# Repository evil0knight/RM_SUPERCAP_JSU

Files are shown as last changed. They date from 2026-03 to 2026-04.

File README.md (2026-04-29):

# RM 超级电容控制器

本仓库整合了我的两个 RoboMaster 超级电容控制器项目。

| 项目 | 来源 | 主控 | 目录 |
| --- | --- | --- | --- |
| RM_SUPERCAP_JSU | 复刻桂林理工大学 | STM32G431 | [`gui_lin_li_gong/`](./gui_lin_li_gong/) |
| RM_SUPERCAP_JSU_V2 | 复刻香港科技大学 | STM32F334 | [`xiang_gang_ke_ji/`](./xiang_gang_ke_ji/) |

---

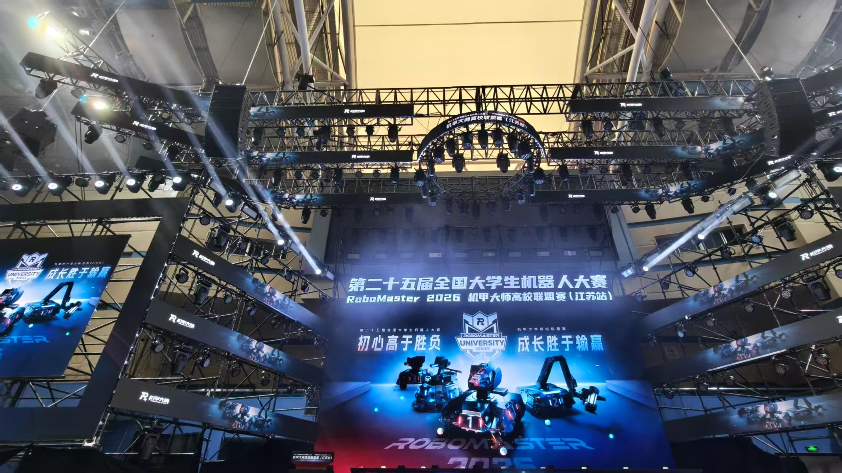
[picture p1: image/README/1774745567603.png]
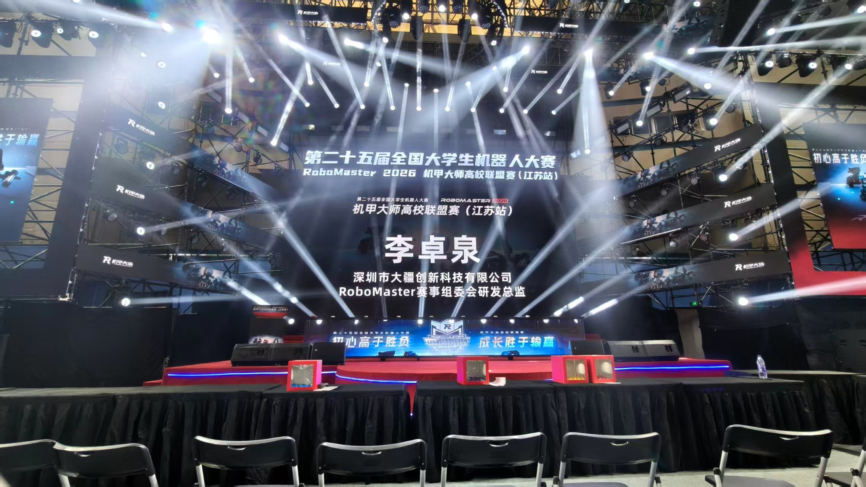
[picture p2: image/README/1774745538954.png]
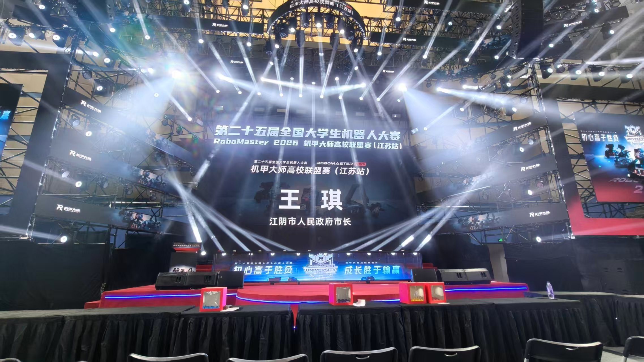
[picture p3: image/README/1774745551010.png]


## 一、RM_SUPERCAP_JSU（复刻桂林理工大学）

复刻 RM 桂林理工大学的开源
我们学校一直没有超电，或许我能填补这个空缺

**10.8**
已经做出来了，上车测试功能完好，能充电能放电，暂时没有遇到问题

**10.19**

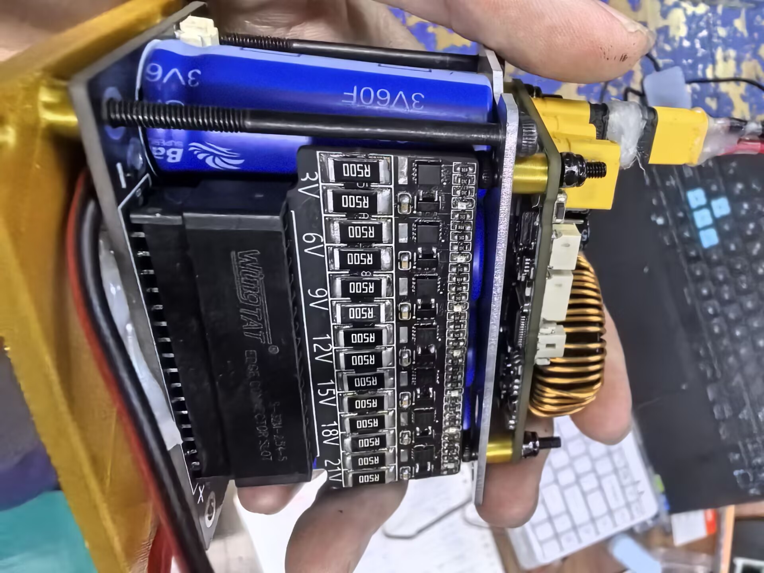
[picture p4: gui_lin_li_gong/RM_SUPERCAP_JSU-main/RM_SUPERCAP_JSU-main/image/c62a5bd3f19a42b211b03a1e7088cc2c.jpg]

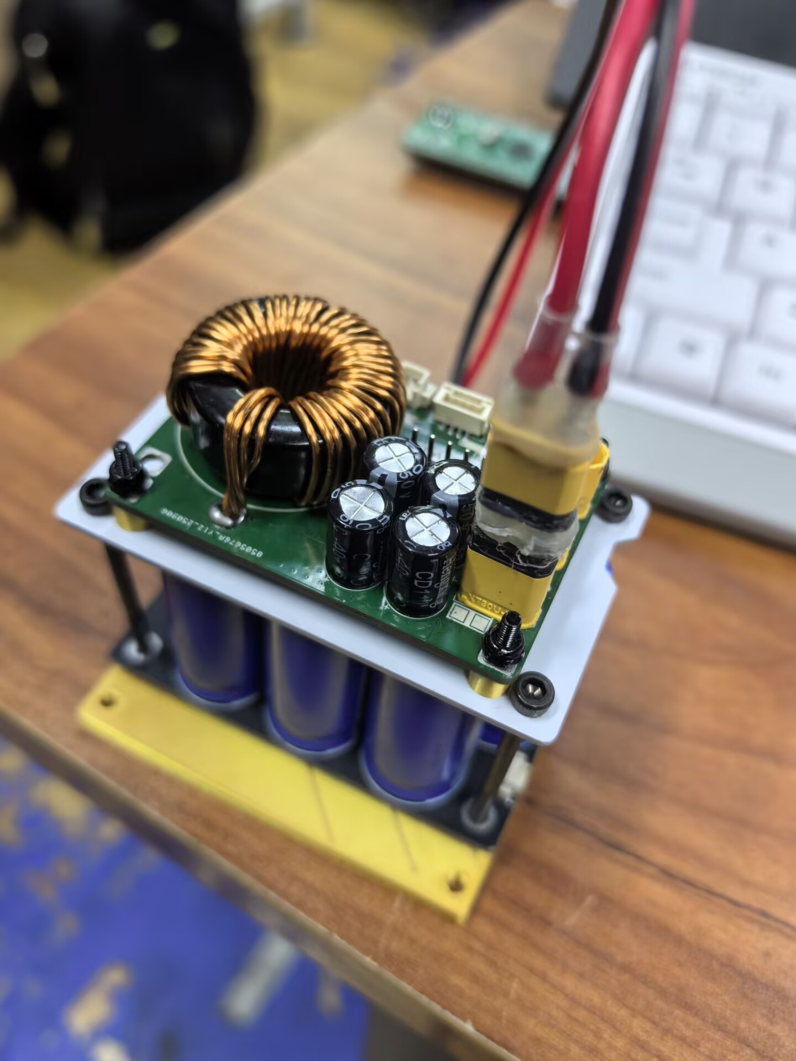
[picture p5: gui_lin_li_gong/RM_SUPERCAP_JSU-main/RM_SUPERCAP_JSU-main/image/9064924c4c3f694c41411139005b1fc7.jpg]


---

## 二、RM_SUPERCAP_JSU_V2（复刻香港科技大学）

复刻香港科技大学

**11.1**
现在的问题是电容端口短路，初步怀疑是原件选型错误，解决方法：加上了群里的同学一起讨论，和队里的研究生一起排查，看研究生的学习笔记，学习 C++

**11.13**
GAME WILL OVER，lucky，终于冲放电成功了，不报错，不过另一个的上板电流采样芯片可能坏了，等快递

**11.15**
研究生学姐走了，剩下的成果归本人所有

**11.18**
第二个也做出来了，一开始错误的原因是底盘电流检测芯片选型错误，要 INA240PW1 才是对的，INA240PW2 的增益是不同的
这如此种种也不过如此啊

**11.19**
炸了....

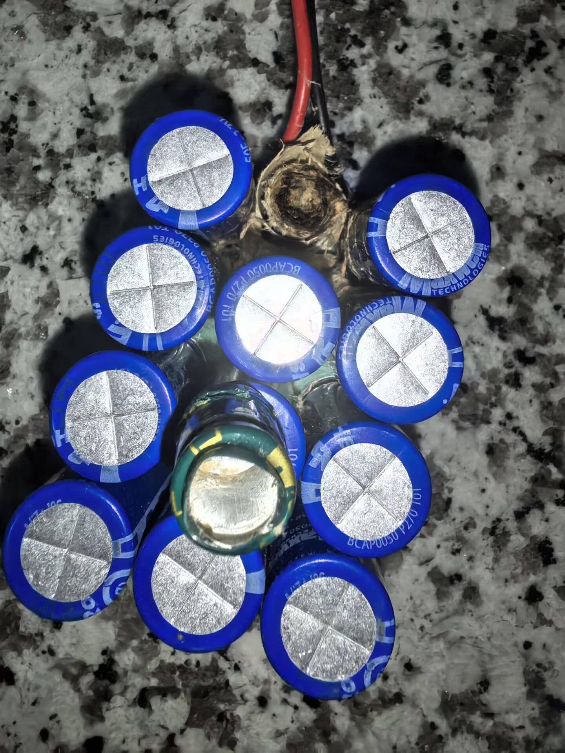
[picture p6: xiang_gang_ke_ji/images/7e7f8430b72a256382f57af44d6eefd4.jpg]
炸了


**11.20**
上车正常，最终效果：可以成功存储能量，要用的时候再输出，根据功率自动选择存储还是释放，功率闭环 + 缓冲能量闭环

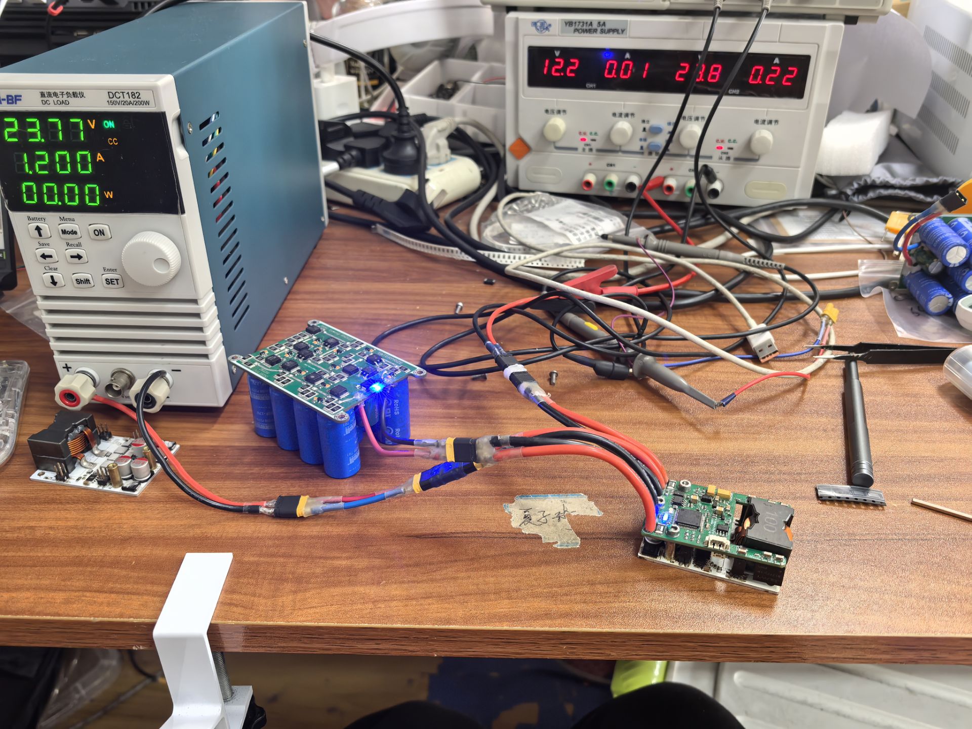
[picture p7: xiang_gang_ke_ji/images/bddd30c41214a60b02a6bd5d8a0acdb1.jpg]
上车


## 2026/4/28

我准备拿香港科技大学的硬件基础,重新写一遍程序,因为他里面有些地方有问题,很多人都是看不懂他们的代码,他们拿C++写的,就是为了炫技,同学们看不懂代码确实不好调,我拿C语言重新写一遍,不过这个项目要在打完所有比赛再开始,也算是我人生中为大学里的竞赛留下最后一点痕迹

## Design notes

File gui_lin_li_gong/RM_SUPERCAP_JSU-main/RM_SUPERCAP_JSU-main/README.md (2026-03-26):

# RM_SUPERCAP_JSU
复刻RM桂林理工大学的开源  
我们学校一直没有超电,或许我能填补这个空缺  

**10.8**  
已经做出来了,上车测试功能完好,能充电能放电,暂时没有遇到问题  
**10.19**  
示例图片
示例图片  
# SUPERCAP 超级电容控制器

基于 STM32G431 的 RoboMaster 超级电容功率控制系统

---

## 项目简介

SUPERCAP 是专为 RoboMaster 机器人设计的超级电容功率控制器。通过双向 BUCK-BOOST 电路实现超级电容的充放电管理，配合 CAN 总线通信与主控板协同工作，提升机器人瞬时功率输出能力。

---

## 工作原理

### 系统架构

控制器通过 CAN 总线接收 RM 主控板发送的以下指令：
- 系统使能信号
- 充电/放电模式切换
- 底盘功率上限
- 充电功率设定

### 充电模式

使用 BUCK-BOOST 电路对超级电容充电，实时检测充电电流和功率，通过 PID 算法控制 NMOS 栅极 PWM，精确调节充电电压。

### 放电模式

使用 BUCK-BOOST 电路向底盘供电，实时检测放电电流和电压，动态调整占空比以控制放电功率，满足功率限制要求。

---

## 硬件设计

### 核心器件

| 功能 | 型号 | 规格 |
|-----|---|---|
| 主控芯片 | STM32G431CBT6 | ARM Cortex-M4, 170MHz |
| 栅极驱动 | EG2181 | 高速半桥驱动器 |
| 半桥 MOS | WSD40120DN56G | 40V/120A |
| 关断 PMOS | WSD40L60DN56 | 40V/60A |
| 储能电感 | 106-125 磁环 | 22µH |
| 母线电流采样 | INA139 | 高侧电流检测 |
| 电容电流采样 | INA181A2 | 双向电流检测 |
| 辅助电源 | JW5026 + RT9193 | DC-DC + LDO |

### 设计工具

本项目使用 **KiCad 8.0** 进行硬件设计。

---

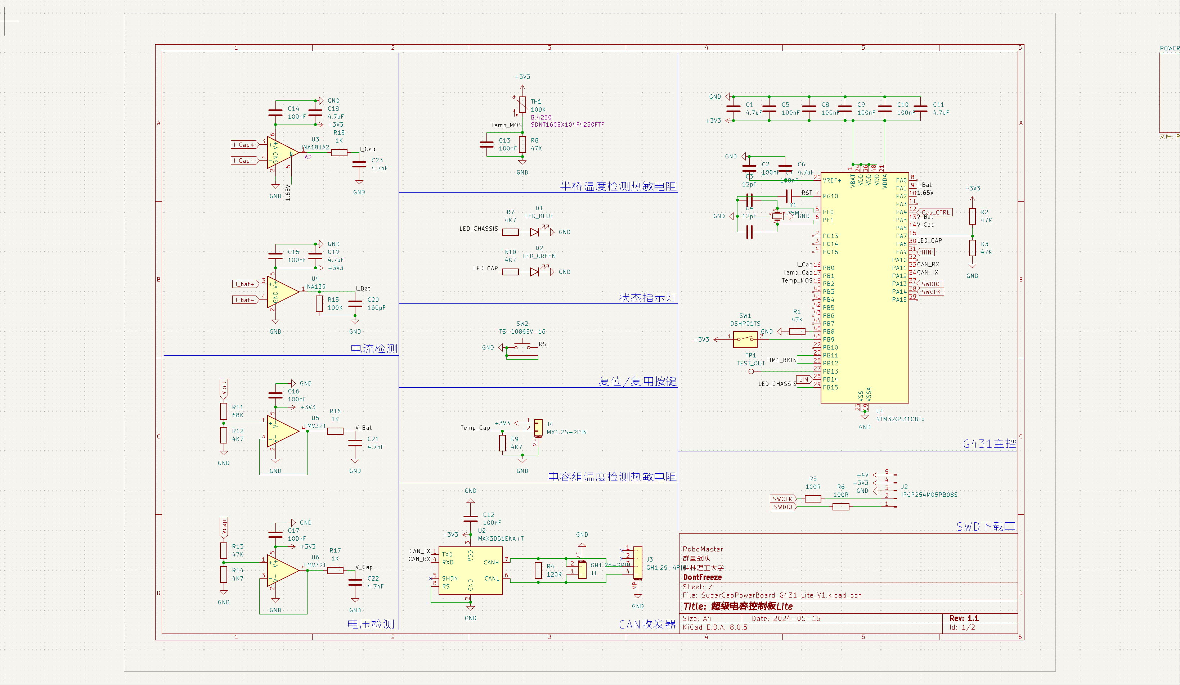
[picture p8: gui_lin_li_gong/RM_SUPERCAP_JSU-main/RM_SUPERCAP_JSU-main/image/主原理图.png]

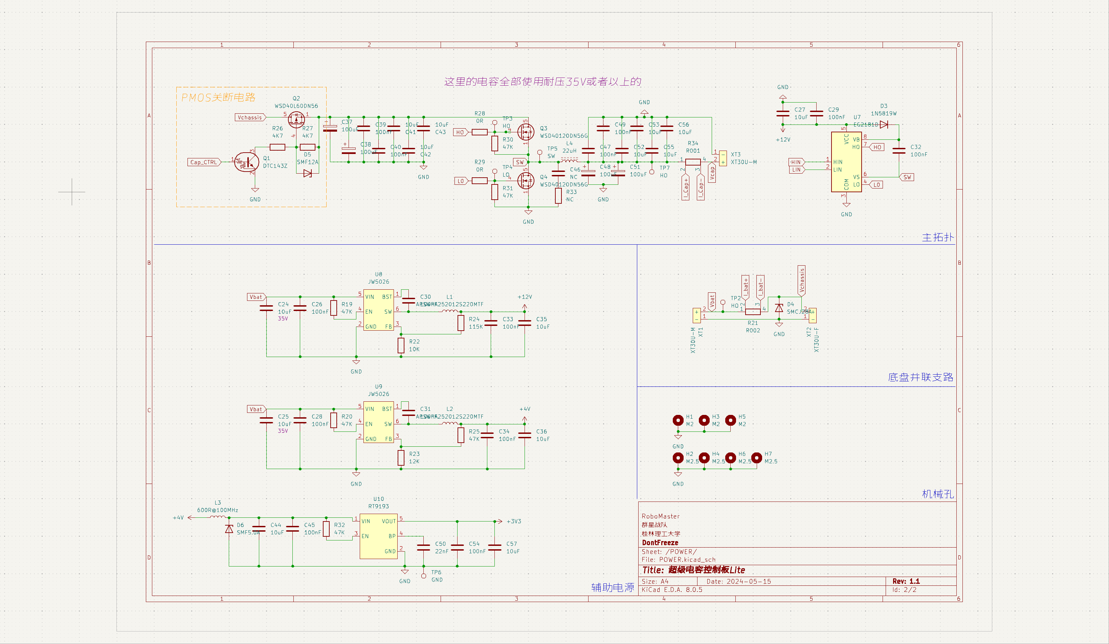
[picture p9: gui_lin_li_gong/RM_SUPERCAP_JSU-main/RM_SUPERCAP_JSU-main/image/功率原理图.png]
  

---
> **本项目主要面向HR。**

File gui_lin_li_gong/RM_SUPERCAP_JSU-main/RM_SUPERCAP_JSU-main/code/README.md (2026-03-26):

# 超级电容控制系统

## 🎯 主要功能
这是一个超级电容充放电控制系统，实现了智能功率管理、多重保护机制和CAN通信功能。

## 📊 系统架构

### 核心主函数
```c
void A_Timing_Ranking_Idea(void){
    TEST_OUT_HIGH;
    TimingCNT++;

    ADC_Convert_To_Reality();

    State_Change();
    Power_Loop();

    ADC_Value_AVG_Compute(DIV512); // 运行频率：100K/512 = 190hz

    if ((TimingCNT & DIV512) == 1) Power_Calculations();        // 运行频率：100K/128 = 190hz
    if ((TimingCNT & DIV512) == 2) Can_SendMess(&sCAN_TX_data); // 运行频率：100K/128 = 190hz
    // 计算平均值、功率计算、CAN发送。数据更新将以最慢的那个为准。

    if ((TimingCNT & DIV1024) == 10) CAN_ReceiveDataRefresh_Flag = 1; //刷新频率：100K/1024 = 97hz
    if ((TimingCNT & DIV8192) == 3) Temperature_Calculations(); // 运行频率：100K/8192 = 12hz
    if ((TimingCNT & DIV8192) == 10) LED_Refresh();             // 运行频率：100K/8192 = 12hz
    if ((TimingCNT & DIV8192) == 10) HAL_IWDG_Refresh(&hiwdg);  // 运行频率：100K/8192 = 12hz

    TEST_OUT_LOW;
}
```

> 💡 **建议**: 看代码时可以复制到新窗口，`A_Timing_Ranking_Idea(void)` 是整个系统的总脉络

## 🔧 关键函数说明

| 函数名 | 功能描述 | 运行频率 |
|---|---|---|
| `State_Change()` | 状态检测与切换 | 100KHz |
| `Power_Loop()` | 根据状态执行功率控制 | 100KHz |
| `ADC_Value_AVG_Compute()` | 计算ADC平均值供操作手查看 | 190Hz |
| `Power_Calculations()` | 功率计算并显示给操作手 | 190Hz |
| `Can_SendMess()` | CAN数据发送（已配置） | 190Hz |
| `Temperature_Calculations()` | 温度计算 | 12Hz |
| `LED_Refresh()` | LED状态刷新 | 12Hz |

### 🛠️ 初始化函数

- **`ADC_Curve_Fitting()`** - UID准备函数
- **`FDCAN_Filter_Init()`** - CAN通讯初始化
- **`Power_Loop_Parameter_Init()`** - 充放电参数初始化

## 📋 系统状态定义

### 超级电容状态枚举
```c
typedef enum
{
  DISCHARGE = 0,              // 放电
  CHARGE = 1,                 // 充电
  WAIT = 2,                   // 等待
  SOFRSTART_PROTECTION = 3,   // 软启动保护
  OCP_PROTECTION = 4,         // 过流保护
  OVP_BAT_PROTECTION = 5,     // 电池过压保护
  UVP_BAT_PROTECTION = 6,     // 电池欠压保护
  UVP_CAP_PROTECTION = 7,     // 电容欠压保护
  OTP_PROTECTION = 8          // 过温保护
} SuperCapStateTypeDef;
```

### 超级电容就绪状态
```c
typedef enum
{
  UNREADY = 0,    // 未就绪
  READY = 1,      // 就绪
} SuperCapReadyTypeDef;
```

## 🏷️ 数据结构

### 状态标志位
```c
typedef struct{
  uint8_t SoftStart_bit;     // 超级电容软起动
  uint8_t Charge_bit;        // 超级电容充电(1充电，0放电)
  uint8_t Enable_bit;        // 超级电容使能(1使能，0失能)
  
  uint8_t CAN_Offline_bit;   // 控制板CAN离线检测(1离线，0在线)
  uint8_t UVP_Bat_bit;       // 电池欠压保护(1欠压，0正常)
  uint8_t UVP_Cap_bit;       // 电容组过放保护(1过放，0正常)
  uint8_t OTP_MOS_bit;       // 控制板温度保护(1过温，0正常)
  uint8_t OTP_CAP_bit;       // 电容组过温保护(1过温，0正常)
  uint8_t OCP_bit;           // 控制板过流保护(1过流，0正常)
  uint8_t OVP_Cap_bit;       // 电容组过压保护(1过压，0正常)
  uint8_t OVP_Bat_bit;       // 控制板过压保护(1过压，0正常)
} StateFlagsTypeDef;
```

> 📝 **注释**: 本来计划使用位域定义，但调试时发现位域变量不显示变量名，因此使用uint8类型

### CAN通信数据结构

#### 📥 接收数据（电控发送）
```c
typedef struct {
  uint8_t Charge;                    // 充电控制(1充电，0放电)
  uint8_t Enable;                    // 使能控制(1使能，0失能)
  uint8_t PowerLimit;                // 裁判系统功率限制
  uint8_t ChargePower;               // 超级电容充电功率
  uint8_t Dead;                      // 机器人死亡状态(未使用)
  float PowerLimitAfterOffset;       // 偏移后功率限制
  float ChargePowerAfterOffset;      // 偏移后充电功率
} CAN_ReceiveDataTypeDef;
```

#### 📤 发送数据（发送给电控）
```c
typedef struct {
  uint8_t SuperCapEnergy;            // 超级电容可用能量(0-100%)
  uint8_t ChassisPower;              // 底盘实时功率(0-255W)
  SuperCapReadyTypeDef SuperCapReady; // 超级电容可用标志
  SuperCapStateTypeDef SuperCapState; // 超级电容状态标志
  uint8_t VoltageBat;                // 电池电压*10
  uint8_t DebugOut_BatPower;         // 调试输出电池功率
  int8_t DebugOut_SuperCapPower;     // 调试输出超电功率
} CAN_TransmitDataTypeDef;
```

### ADC数据结构
```c
typedef struct {
  uint32_t Vcap;    // 电容电压
  uint32_t Vbat;    // 电池电压
  uint32_t Ibat;    // 电池电流
  uint32_t Icap;    // 电容电流
  uint32_t Tmos;    // MOS管温度
  uint32_t Tcap;    // 电容温度
} ADC_ValueTypeDef;
```

> ⚠️ **注意**: 该结构体用途多样 - 既作为累加求和使用，也用于平均值计算，还用于瞬时控制

## 🚀 核心控制流程

### 1. 系统初始化
```c
void Power_Loop_Parameter_Init(void){
    TIM1_PWM2_BREAK;           // 关闭半桥PWM，防止初始值导致意外
    PMOS_OFF;                  // 关闭PMOS
    
    // 初始状态设置
    sStateBit.SoftStart_bit = 1;    // 开机必须软启动
    sStateBit.Charge_bit = 1;       // 默认充电状态
    sStateBit.Enable_bit = 0;       // 等待CAN使能
    sStateBit.CAN_Offline_bit = 1;  // 默认CAN离线
    
    // PID参数初始化
    // Buck电压环PID
    sPID_buck_V.Kp = PID_BUCK_V_KP;
    sPID_buck_V.Ki = PID_BUCK_V_KI;
    // ... 其他PID参数
}
```

### 2. 软启动保护
```c
void Soft_Start_Loop(void){
    // 软启动期间PMOS关闭，通过寄生二极管小电流充电
    if (sCAN_RX_data.Charge && sCAN_RX_data.Enable) {
        // 电流环控制
        PID_Compute(&sPID_buck_I, Icap, SOFTSTART_CHARGE_ICAP, &PID_CurrentLoopOut);
        // 电压环控制
        PID_Compute(&sPID_buck_V, Vcap, SOFTWARE_OVP_VCAP, &PID_VoltageLoopOut);
        
        // PWM输出竞争选择最小值
        Loop_Competition_Buck(PID_CurrentLoopOut, PID_VoltageLoopOut, &TIM1_PWM2_Comapre);
        
        // 设置PWM和ADC采样时间
        SET_PWM_COMPARE(TIM1_PWM2_Comapre);
        SET_ADC_TRIGGER_COMPARE((TIM1_PWM2_Comapre >> 3) + (TIM1_PWM2_Comapre >> 2));
        
        SuperCap_Enable();
    }
    
    // 充电到5V以上退出软启动
    if (Vcap > 5) {
        SaftChargeOutDelay++;
        if (SaftChargeOutDelay >= COUNT_TO_1S_ON_100Khz && sCAN_RX_data.Charge == CHARGE) {
            sStateBit.SoftStart_bit = 0;
            sStateBit.UVP_Cap_bit = 1;
        }
    }
}
```

### 3. 充电控制
```c
void Charge_Loop(void){
    // 安全功率限制
    SafeChargePcap = Vcap * SAFE_CHARGE_ICAP;
    P_ChargeCap = (sCAN_RX_data.ChargePowerAfterOffset > SafeChargePcap) ? 
                  SafeChargePcap : sCAN_RX_data.ChargePowerAfterOffset;
    
    // 功率环控制
    Pcap = Vcap * Icap;
    PID_Compute(&sPID_PowerLoop_Charge, Pcap, P_ChargeCap, &PID_PowerLoopOut);
    
    // 电压环控制
    PID_Compute(&sPID_buck_V, Vcap, SOFTWARE_OVP_VCAP, &PID_VoltageLoopOut);
    
    // 双环控制竞争
    Loop_Competition_Buck(PID_PowerLoopOut, PID_VoltageLoopOut, &TIM1_PWM2_Comapre);
    
    // 断电检测
    Power_Down();  // 检测电池电流，过低时失能电容组
}
```

### 4. CAN通信管理
```c
// 接收回调
void HAL_FDCAN_RxFifo0Callback(FDCAN_HandleTypeDef *hfdcan, uint32_t RxFifo0ITs){
    HAL_FDCAN_GetRxMessage(&hfdcan1, FDCAN_RX_FIFO0, &sFDCAN1_RxHeader, CAN_RX_Buff);
    CAN_WDG_Count = 0;  // 清零离线计数
}

// 离线处理
void CAN_Offline_Loop(void){
    SuperCap_Disable();
    // 清除所有PID积分
    
    if (CAN_WDG_Count == 1) {
        CAN_ONline_Delay++;
        // 连续收到10次充电指令才判断在线
        if (CAN_ONline_Delay >= 10 && sCAN_RX_data.Charge == CHARGE) {
            sStateBit.CAN_Offline_bit = 0;
        }
    }
}
```

## ⚡ PID控制说明

系统采用多环PID控制：
- **电压环**: 限制最大电压防止过压
- **电流环**: 限制最大电流防止过流  
- **功率环**: 控制充放电功率

> 🔧 **技巧**: 每个电压值对应特定占空比，通过 `PID->OutMax * 0.04f` 计算电压-占空比比例关系

## 📱 使用说明

1. **上电流程**: 系统自动进入软启动模式
2. **CAN通信**: 等待电控发送使能和充电指令
3. **状态监控**: 通过CAN实时上报系统状态
4. **保护机制**: 多重硬件和软件保护确保安全

## 🛡️ 安全特性

- ✅ 软启动保护防止冲击
- ✅ 过压/欠压保护
- ✅ 过流保护
- ✅ 过温保护  
- ✅ CAN通信看门狗
- ✅ 断电检测

---

> 💻 **开发建议**: 复制代码到新窗口查看，便于理解整体架构

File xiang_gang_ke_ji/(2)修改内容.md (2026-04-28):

# (2)修改

[←返回傻瓜使用教程](超电傻瓜式使用教程.md)

---

> 第二批买回来的原件,INA电流检测不准,具体点的问题是每次上电,I_A_CONVERT_BIAS都会变,基准值会变,光靠拟合是没用的,所以需要写一个补丁

> 所以我在每次上电的时候,读取IA和IB为0的时候的SampleManager::adcIA.sum和SampleManager::adcIB.sum

```
宏展开：
I = GAIN * (sum / 8) + BIAS
当 I = 0 时：
0 = GAIN * (sum_zero / 8) + BIAS
=> BIAS = -GAIN * (sum_zero / 8)
  所以只要在 I 确实为 0 的时候，读出 sum_zero，就能算出当次上电的 BIAS。
```

```
为什么 GAIN 不漂？
  GAIN 对应的是传感器的灵敏度（每安培对应多少 ADC 计数），这由硬件电阻、参考电压决定，温漂很小。
  为什么 BIAS 会漂？
  BIAS 对应的是零点电压，INA 运放的输入失调电压每次上电会有微小变化，导致 I=0 时 ADC 读数不固定，所以每次上电重新测一次零点。
```

```
前提条件：
校准时被测电流必须真的是 0
iA、iB 满足（buckboost 未工作）
iReferee 不满足（因为超电被供电的瞬间,电流是从电源端reference流向底盘chassis的,电流无法为0,除非先把连接底盘的xt30拔出来），所以不能动态校准
```

Core\Inc\calibration.hpp

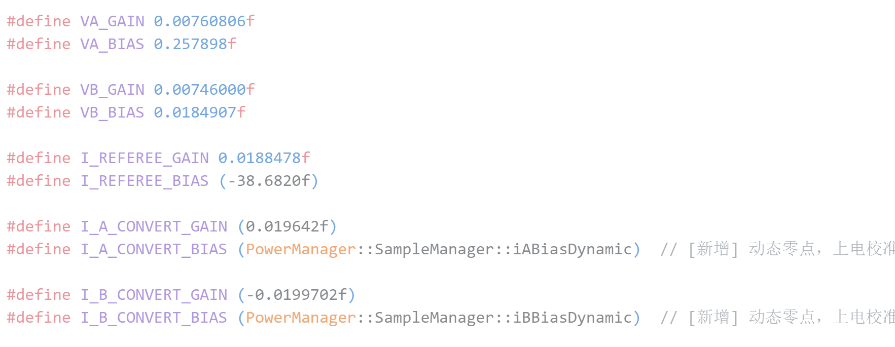
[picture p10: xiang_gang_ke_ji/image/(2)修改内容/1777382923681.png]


Core\Inc\PowerManager.hpp

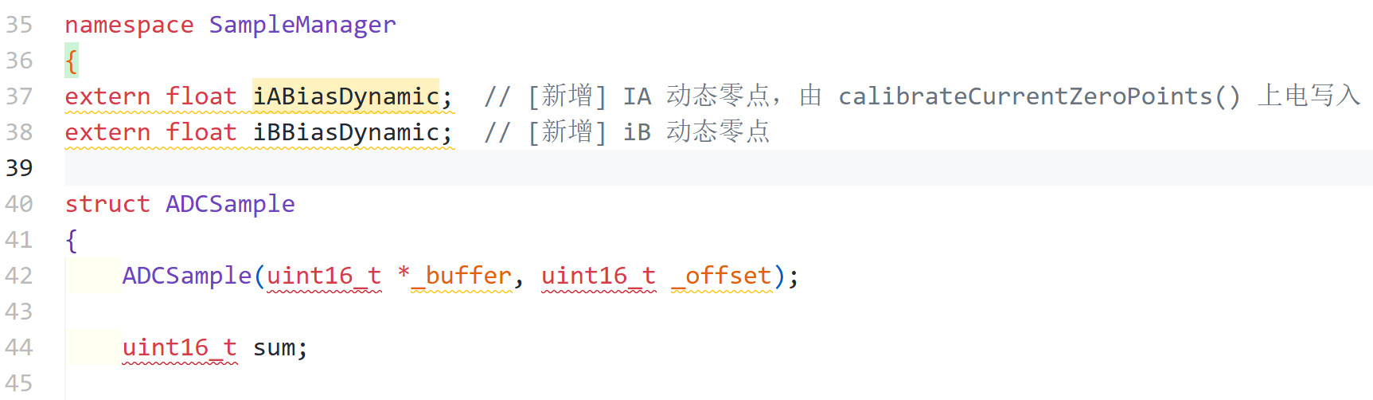
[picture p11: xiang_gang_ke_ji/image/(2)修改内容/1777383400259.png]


Core\Src\PowerManager.cpp

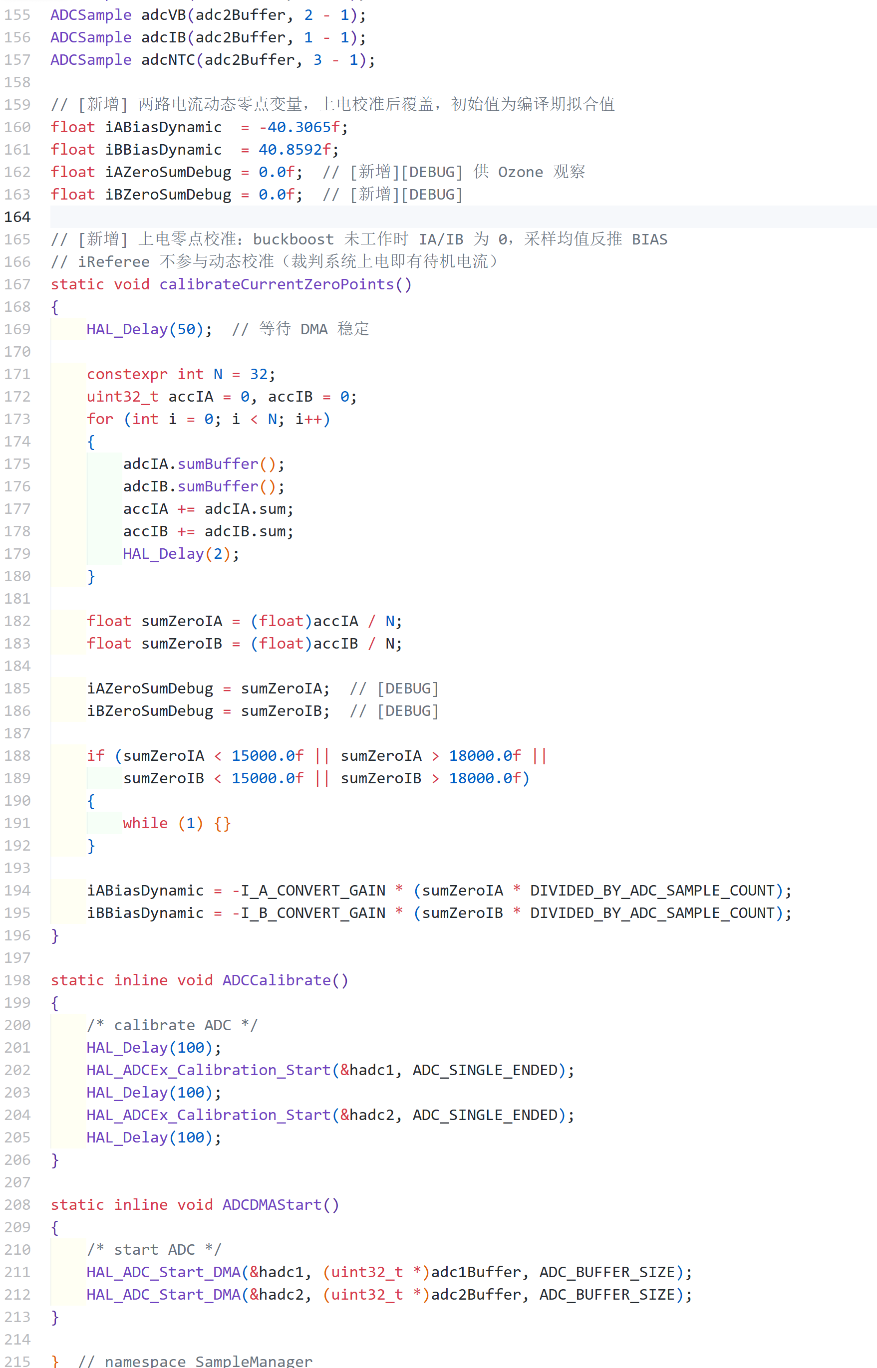
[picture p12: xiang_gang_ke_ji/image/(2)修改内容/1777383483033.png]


要是动态拟合有问题,超电会卡住while(1)

Core\Src\PowerManager.cpp

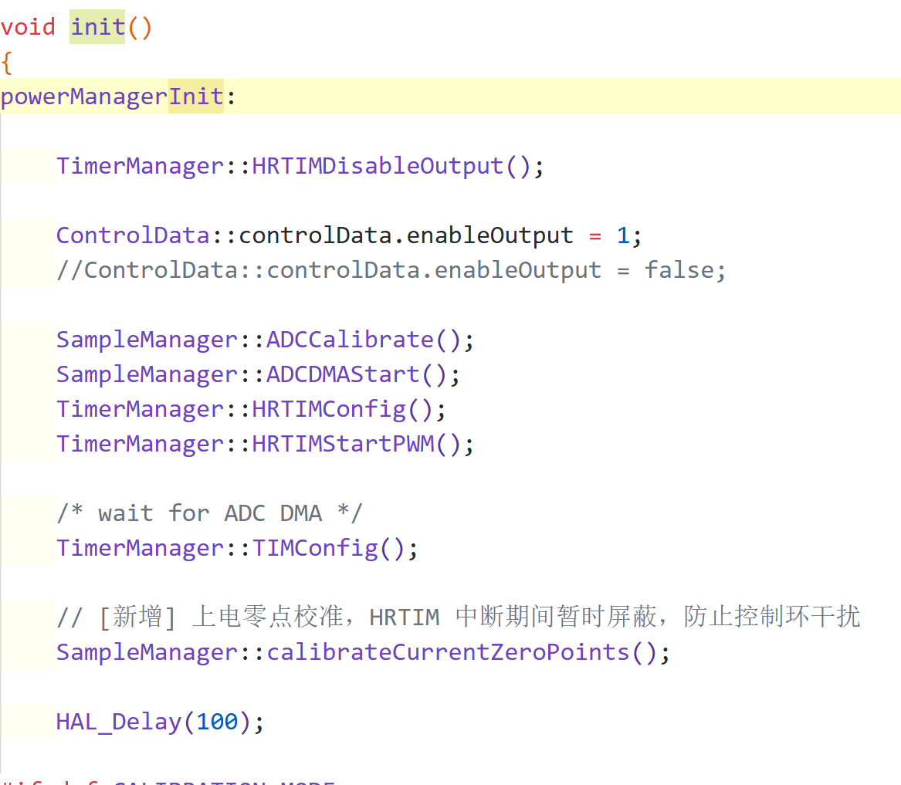
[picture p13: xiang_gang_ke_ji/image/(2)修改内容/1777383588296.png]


iReferee没办法了,超电没法阻断电流,但是没有动态拟合测算出来也差不多,没啥问题,

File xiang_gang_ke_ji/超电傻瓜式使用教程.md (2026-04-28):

# 超电傻瓜式使用教程

> 正常使用的超电不要改代码,下面的步骤是为了新做24超电,新作超电使用(2)
>
> (325)这个是给最早的两个超电,里面拟合好像有些不对,有时会报短路报错(不知道为什么,我猜还是拟合问题),需要车子一直给使能,不过能用,就留着吧
>
> (2)这个是新的超电,里面有修改原版代码,因为第二批买回来的INA芯片采样不准,每次上电的基准值都会发生变化,所以有修改

[(2)修改内容](2)修改内容.md)

## 📥 第一步：下载代码

这个编译学学可以，下载用OZONE
使用 **OZONE + JLink** 进行代码下载。
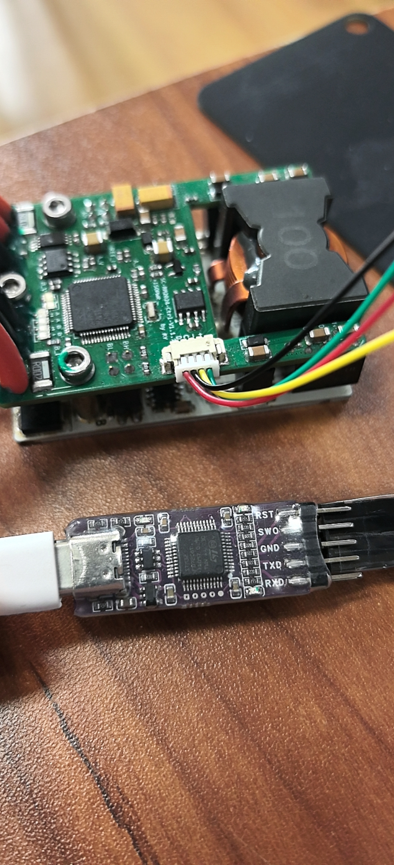
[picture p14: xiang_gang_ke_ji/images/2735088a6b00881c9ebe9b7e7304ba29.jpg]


---

## 🔧 第二步：修改硬件ID（新做超电必做）

如果要新做超电，**必须**使用 **STM32CubeProgrammer** 修改硬件ID。

### 操作步骤：

1. 打开 STM32CubeProgrammer
2. 连接设备
3. 将硬件ID修改为 **10x**

> 如果不修改硬件ID，(325)会无法下载,(2)蜂鸣器会一直响

> **操作示例：**
> 请参考示例图片进行操作
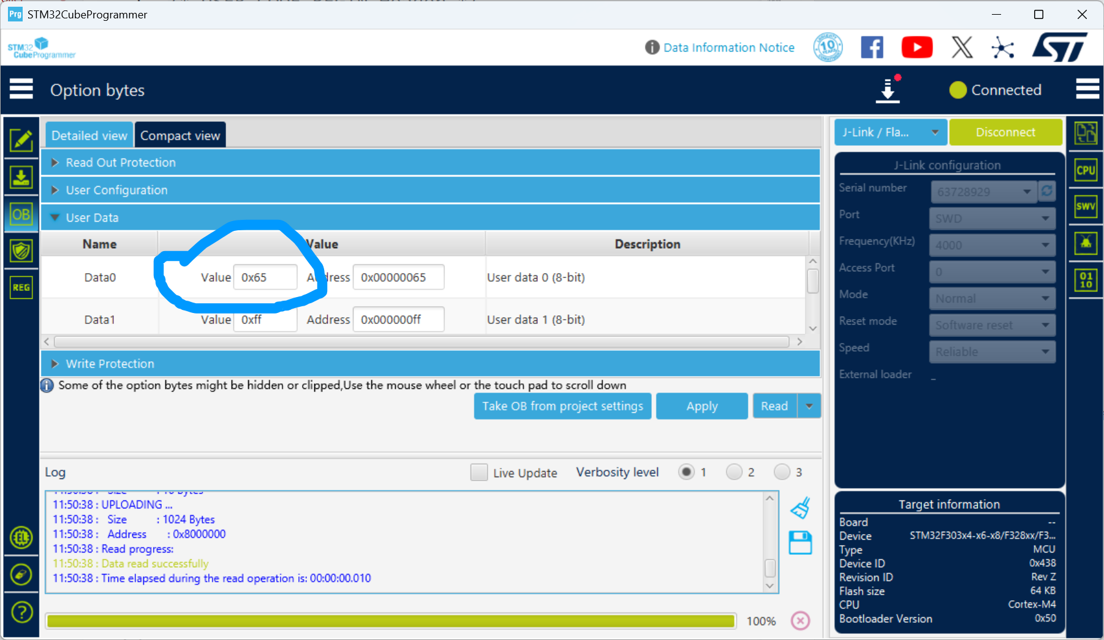
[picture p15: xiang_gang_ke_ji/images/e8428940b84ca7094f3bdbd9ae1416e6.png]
> 

---

## 第三步:编译

1. **ARM GCC 工具链** - `arm-none-eabi-gcc`
2. **CMake** - 版本 3.22 或更高
3. **Ninja** - 构建工具
4. **Git Bash** - Windows 环境下需要

### 📝 在 Git Bash 中编译

#### 1. 打开 Git Bash

在项目目录中右键，选择 "Git Bash Here"

#### 2. 给脚本添加执行权限（首次运行）

```bash
chmod +x build.sh
```

#### 3. 运行编译脚本

```bash
# 指定 HARDWARE_ID
./build.sh 101
```

## 第四步：测试

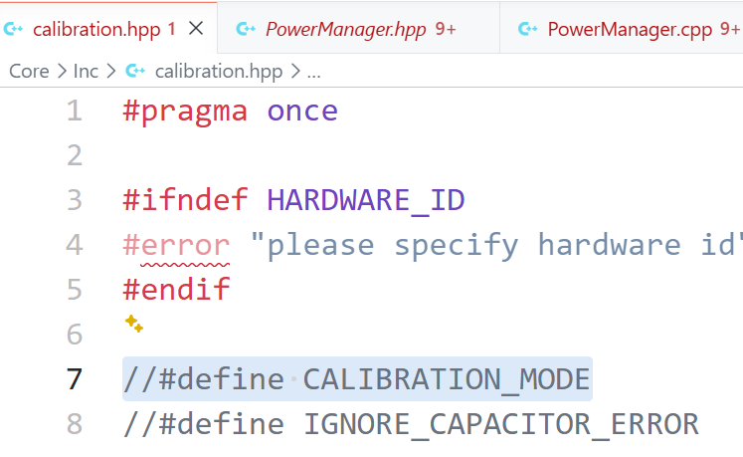
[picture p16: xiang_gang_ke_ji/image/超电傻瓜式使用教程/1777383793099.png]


这里取消注释

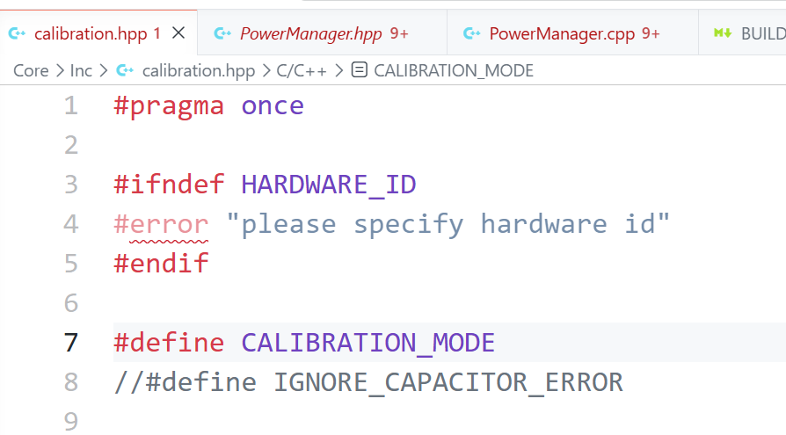
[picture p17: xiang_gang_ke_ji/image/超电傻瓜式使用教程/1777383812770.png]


然后编译,(2)会把上管打开,下管关闭

先开电源,然后下载进去,运行

此时应该是电源电压和负载仪的电压电流差不多,此时读出来的I就是要用来拟合的

---

## 拟合

拟合数据记录,然后丢给AI,让他帮你改Core\Inc\calibration.hpp这里的数值

这是IA端拟合示例

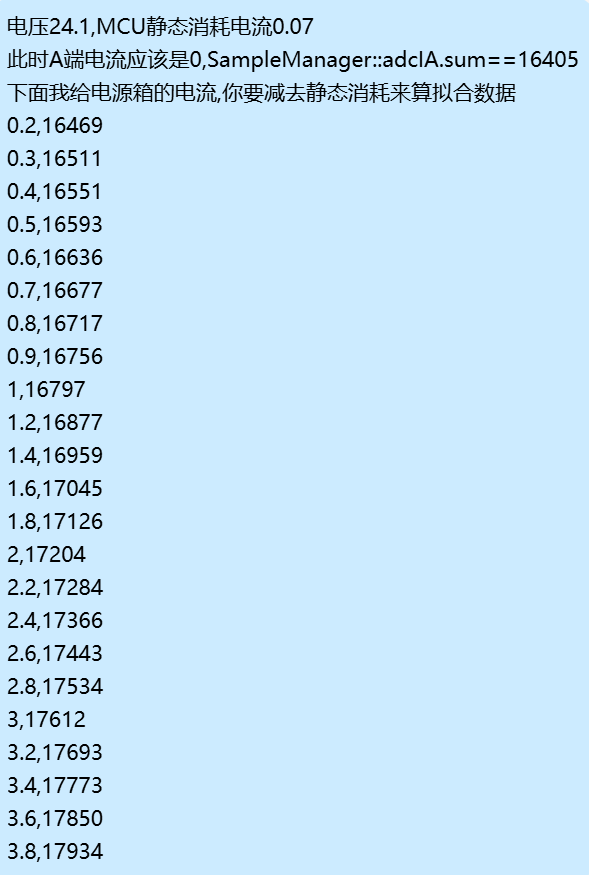
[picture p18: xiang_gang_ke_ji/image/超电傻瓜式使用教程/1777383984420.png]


VA拟合示例

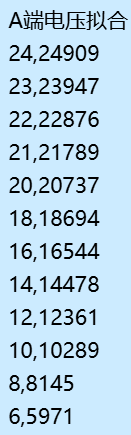
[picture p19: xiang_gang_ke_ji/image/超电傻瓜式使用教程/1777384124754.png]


B端拟合示例

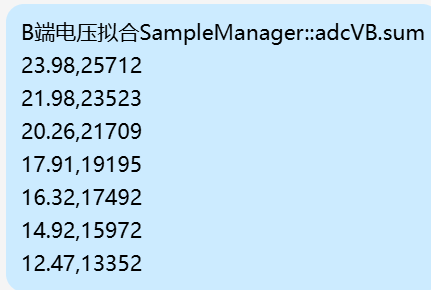
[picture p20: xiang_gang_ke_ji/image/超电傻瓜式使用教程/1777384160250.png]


IB拟合

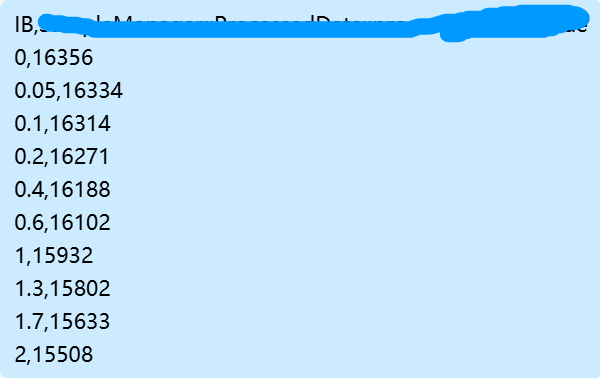
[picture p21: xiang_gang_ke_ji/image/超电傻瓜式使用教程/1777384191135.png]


ireference拟合示例

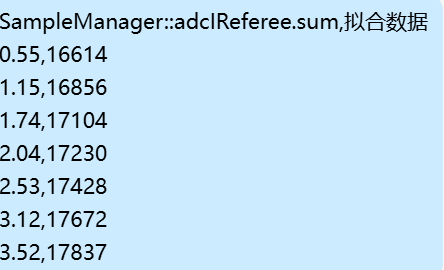
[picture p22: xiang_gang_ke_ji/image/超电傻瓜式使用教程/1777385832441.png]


拟合好就改回去//#define CALIBRATION_MODE

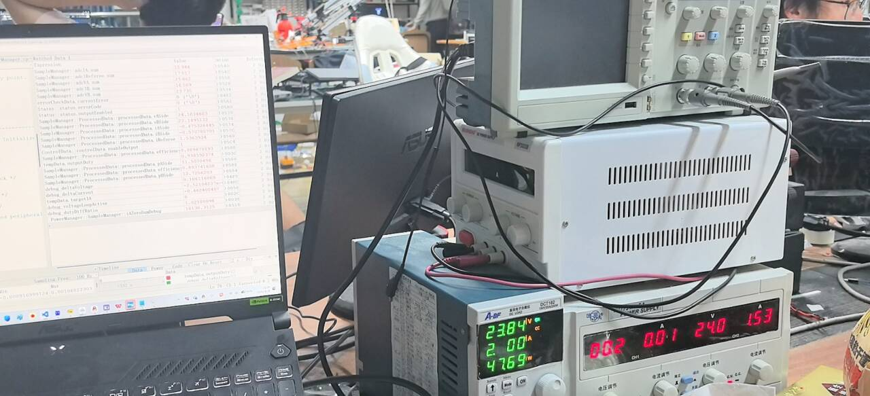
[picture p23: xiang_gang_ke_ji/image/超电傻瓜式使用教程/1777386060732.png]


---

## 🔌 接线说明

### 端口连接示意（从正面看）

```
┌─────────────────────────────────┐
│  左侧        中间        右侧    │
│ 电源(电管)  底盘(中心板)  电容   │
│  电流流入    电流流出    储能端  │
└─────────────────────────────────┘
```

- **右边**：接电容
- **中间**：接底盘（中心板）—— 电流流出
- **左边**：接电源（电管）

> **接线示例：**
> 请参考示例图片进行操作
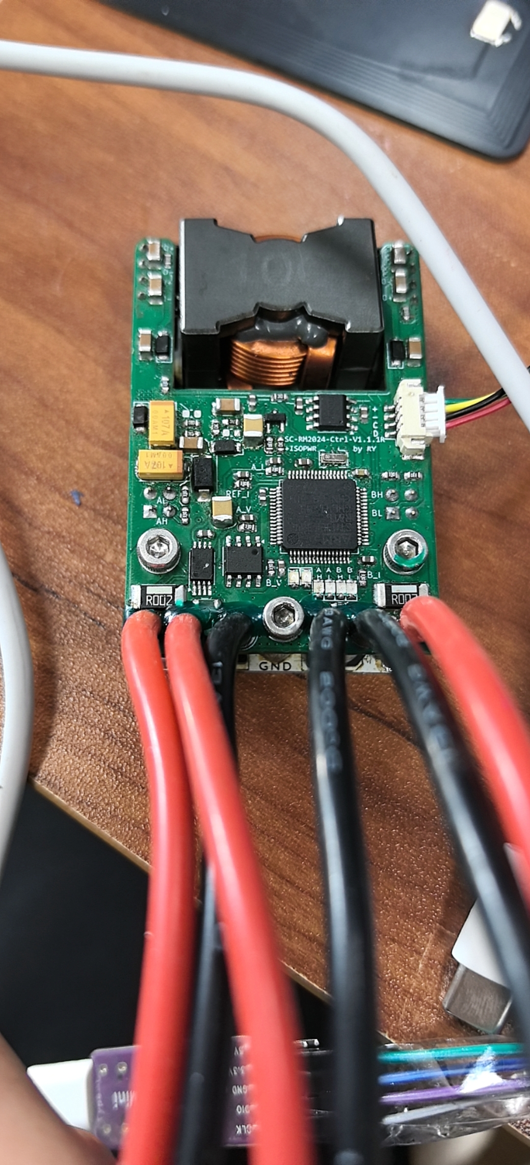
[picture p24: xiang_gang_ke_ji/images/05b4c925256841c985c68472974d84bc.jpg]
> 

---

## 🏁 超电裁判系统接法

> **接线示例：**
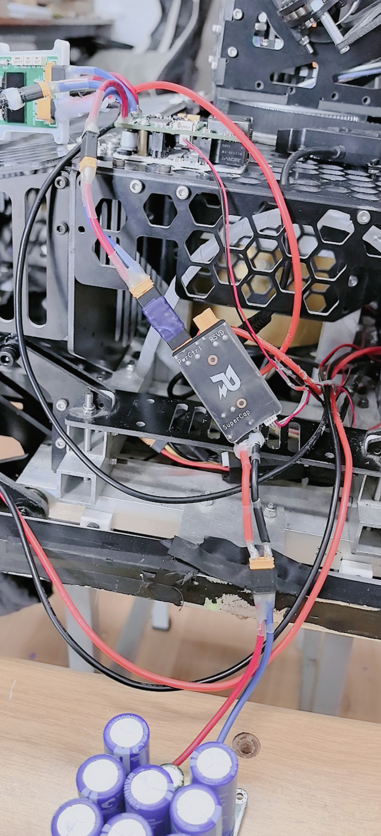
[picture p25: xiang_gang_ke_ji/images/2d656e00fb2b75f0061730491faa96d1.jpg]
> 

---

## 📡 第五步：CAN通信配置

xiang_gang_ke_ji\super_cap_extract_20260428
这里放的是车上的超电相关代码配置,我让AI读了英雄车上的代码,没怎么看
里面应该有个程序,好像是几秒就使能一下超电,这是因为最老的两个超电容易短路保护,这很奇怪,所以就一直使能就好了

---

## ✅ 完成

按照以上步骤操作，超电即可正常使用！1级580W的最大可使用功率!

---

*文档最后更新：2026/4/28*

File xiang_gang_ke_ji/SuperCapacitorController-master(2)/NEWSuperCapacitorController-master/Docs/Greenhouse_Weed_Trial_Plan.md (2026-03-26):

## 温室杂草识别试验方案（全垄布置）

### 1. 项目目标与地块概况
- **目标定位**：在全封闭温室内建立四条标准垄的杂草识别样地，专门采集低株高（≤`5 cm`）阶段的图像数据，同时保留托盘或边沟小区作种源补充。[2][3][4][7][8]
- **地块结构**：每条垄宽`0.50 m`、长`45.0 m`（面积`22.5 m²`），共四垄，总面积`90 m²`；垄间设置`0.30 m`巡查通道并铺防草布，垄尾保留`1.0 m × 1.0 m`缓冲区用于设备调头与物资堆放。
- **小区划分**：每条垄沿长度方向划分为A/B/C三个连续小区，每小区长`15.0 m`、宽`0.50 m`，面积`7.5 m²`。A/B/C用于重复采样或不同处理（如光照、补光、控水差异）。
- **识别优先原则**：四条垄全部用于识别样本采集，种源补育安排在垄尾托盘或另设基质槽，与主试验区完全隔离，避免影响拍摄。

### 2. 温室环境与通用管理
- **温度与湿度**：白天维持`16~18℃`、夜间`10~12℃`，相对湿度`60~70%`；必要时开启顶部通风与侧膜，防止徒长。[1]
- **光照**：保持棚膜洁净，阴天或冬季可补充LED顶光；如需遮阳，优先在轨道上方设置局部遮光布，保证拍摄光均匀。[1]
- **水肥策略**：播后7天内保持基质湿润，使用清水滴灌或喷雾；识别阶段停用氮肥，仅补充低浓度（≤`0.5 g/L`）平衡营养液，控制株高≤`5 cm`。[2][3]
- **防扩散措施**：四周加设20 cm深阻根膜，入棚设双门和脚踏消毒池；剪下的植株集中密封处理，防止种子逸散。[2][3]

### 3. 全垄识别布局原则
- **小区编号**：记为“垄号-小区”（例：`L1-A`），结合物种名称和轮次建立编码（例：`L1-A-CYP-01`）。
- **播种策略**：根据物种播幅在小区内布设2~4行，保证叶片铺满但不重叠；所有播量以下述小区面积（`15.0 m × 0.50 m`）为计算基准。
- **托盘补植**：每个物种额外准备2~4个`60 cm × 40 cm × 10 cm`基质托盘，放置在垄尾缓冲区，用于补播或备份。

### 4. 方案一：全垄单物种识别布置

> 轮次之间建议预留1周清园与闷棚时间，保证下一批次无残根残茎干扰。所有小区均保持单物种，便于精确控制密度、株高与背景。[2][3][7]

#### 轮次1（周期0~6周）：香附子 / 稗草 / 牛筋草 / 马唐
- **垄1 香附子**：
  - 小区尺寸：A/B/C各`0.50 m × 15.0 m`。
  - 栽植密度：行距`0.18 m`（3行），穴距`0.18 m`，每穴1块茎。
  - 种植密度：约`31`穴/m²；单小区约`230`穴，整垄约`690`穴。
  - 管理要点：覆土厚度`3 cm`，萌芽后保持株高≤`5 cm`，必要时摘除顶部叶片。[2]
- **垄2 稗草**：
  - 小区尺寸：A/B/C各`0.50 m × 15.0 m`。
  - 播种密度：行距`0.15 m`（4行），株距`0.05 m`。
  - 种植密度：约`133`株/m²；单小区播量约`110 g`（约`14.7 g/m²`），整垄约`330 g`。
  - 管理要点：保持2~3叶期拍摄，喷雾补水避免地表板结。[3]
- **垄3 牛筋草**：
  - 小区尺寸：A/B/C各`0.50 m × 15.0 m`。
  - 播种密度：行距`0.20 m`（3行），株距`0.08 m`。
  - 种植密度：约`63`株/m²；单小区播量约`70 g`（约`9.3 g/m²`），整垄约`210 g`。
  - 管理要点：分蘖超过3株时剪除侧蘖，保持叶片舒展。
- **垄4 马唐**：
  - 小区尺寸：A/B/C各`0.50 m × 15.0 m`。
  - 播种密度：行距`0.20 m`（3行），株距`0.06 m`。
  - 种植密度：约`83`株/m²；单小区播量约`80 g`（约`10.7 g/m²`），整垄约`240 g`。
  - 管理要点：拔节迹象出现即剪顶，结合补光获取均匀图像。[3]

#### 轮次2（周期7~12周）：马齿苋 / 反枝苋 / 小飞蓬 / 灰菜
- **垄1 马齿苋**：3行布局，行距`0.20 m`，株距`0.15 m`；种植密度约`33`株/m²，单小区约`250`株（整垄`750`株）；围设高度`10 cm`的PVC挡板防匍匐。
- **垄2 反枝苋**：3行，行距`0.25 m`，株距`0.10 m`；种植密度约`40`株/m²，单小区播量`50 g`（约`6.7 g/m²`，整垄`150 g`）；控水控肥使株高≤`5 cm`。[4]
- **垄3 小飞蓬**：4行，行距`0.18 m`，莲座株距`0.12 m`；种植密度约`46`株/m²，单小区播量`40 g`（约`5.3 g/m²`，整垄`120 g`），间苗至每小区约200株。
- **垄4 灰菜**：3行，行距`0.25 m`，株距`0.10 m`；种植密度约`40`株/m²，单小区播量`60 g`（约`8.0 g/m²`，整垄`180 g`）；保持植株直立，必要时轻度间苗。

#### 轮次3（周期13~18周）：龙葵 / 酸模叶蓼 / 狗尾巴草 / 蒲公英+车前
- **垄1 龙葵**：2行，行距`0.25 m`，穴距`0.20 m`；种植密度约`20`株/m²，单小区移栽苗约`60`株（整垄`180`株）；控温控氮保持株高≤`5 cm`，果实初显即剪除。[3]
- **垄2 酸模叶蓼**：3行，行距`0.30 m`，株距`0.15 m`；种植密度约`22`株/m²，单小区播量`45 g`（约`6.0 g/m²`，整垄`135 g`）；滴灌带两侧对称布置增强画面整齐度。
- **垄3 狗尾巴草**：4行，行距`0.15 m`，株距`0.10 m`；种植密度约`67`株/m²，单小区播量`60 g`（约`8.0 g/m²`，整垄`180 g`）；通过降温和剪顶将株高控制在`5 cm`以内。
- **垄4 蒲公英+车前**：各物种分配A/B/C小区的半幅（每物种面积`0.50 m × 7.5 m`），莲座密度`0.30 m × 0.20 m`；种植密度约`17`株/m²，单物种小区约`60`株，整垄约`180`株；抽薹即刻剪除。

#### 轮次4（周期19~24周）：附地菜 / 益母草 / 草木犀 / 野豌豆
- **垄1 附地菜群落**：4行，行距`0.20 m`，株距`0.10 m`；种植密度约`50`株/m²，单小区播量`35 g`（约`4.7 g/m²`，整垄`105 g`）；保持莲座状态。
- **垄2 益母草**：3行，行距`0.25 m`，株距`0.12 m`；种植密度约`33`株/m²，单小区播量`40 g`（约`5.3 g/m²`，整垄`120 g`）；株高接近`5 cm`即采集。
- **垄3 草木犀**：3行，行距`0.30 m`，株距`0.15 m`；种植密度约`22`株/m²，单小区播量`45 g`（约`6.0 g/m²`，整垄`135 g`）；低位绳网限制藤蔓高度。
- **垄4 野豌豆**：3行，行距`0.30 m`，株距`0.15 m`；种植密度约`22`株/m²，单小区播量`50 g`（约`6.7 g/m²`，整垄`150 g`）；设置低位绑蔓点保持苗期姿态。

### 5. 方案二：双物种同垄识别布置

> 依据设施混播管理资料，双物种条带或分段种植可提升数据多样性，但需增加隔离带与密度衰减，避免相互遮蔽。[5][11][12][13]

**组合搭配依据**
- 设施温室混播建议：农业农村部智慧种植模式强调可通过条带化或分段混播提升空间利用效率与数据多样性，但需设置隔离带并调低播量，避免相互遮蔽。[5]
- 块茎杂草与禾本科共管：香附子技术要点指出在高湿基质中可与禾本科共享水肥管理，只需降低禾本科播量并留出观测空间，因此组合1选择香附子+稗草并下调稗草密度。[3][11]
- 禾本科密植控制：稗草、牛筋草、马唐等一年生禾本科在密植条件下会相互遮挡，推广意见建议间苗或降低播量，组合2据此分段种植并下调播量以保持株高≤`5 cm`。[3]
- 阔叶杂草共生生态：研究表明马齿苋、反枝苋、小飞蓬、灰菜等阔叶杂草常在同一生境共存，但需控制密度和高度，组合3与组合4依靠分段、剪顶和围挡保持叶片清晰度。[12][13]
- 识别数据多样性：遥感与图像识别研究（WeedMap、DeepWeeds）显示多物种共存样本能提升模型泛化能力，但需维持单株轮廓清晰，因此方案二在保持株高≤`5 cm`的前提下采用条带隔离与密度衰减，兼顾可视性与多样性。[7][8]

- **分区方式**：每条垄仍宽`0.50 m`、长`45.0 m`，沿长度划分为前段（`0~22.5 m`）与后段（`22.5~45 m`）两个亚小区，各面积`11.25 m²`。
- **隔离带**：在两亚小区交界设置`0.5 m`宽防草布缓冲，或铺设可移动PVC板，减少根系互侵与影像干扰。
- **播种原则**：同垄内优先搭配1种禾本科+1种阔叶，或块茎+实生型，通过下调单物种播量20%降低竞争。[5][11]

#### 组合1（垄1：香附子 + 稗草）
- **前段（0~22.5 m）香附子**：行距`0.18 m`（3行），穴距`0.20 m`，每穴1块茎；种植密度约`28`穴/m²，单段约`320`穴，总播块茎`320~330`粒。[11]
- **后段（22.5~45 m）稗草**：行距`0.18 m`（3行），株距`0.06 m`；种植密度约`93`株/m²，单段播量约`150 g`（约`13.3 g/m²`）；通过间苗维持株高≤`5 cm`。[3]

#### 组合2（垄2：牛筋草 + 马唐）
- **前段牛筋草**：行距`0.22 m`（3行），株距`0.10 m`；种植密度约`45`株/m²，单段播量约`100 g`（约`8.9 g/m²`）；出苗后剪除多余分蘖。[3]
- **后段马唐**：行距`0.22 m`（3行），株距`0.08 m`；种植密度约`57`株/m²，单段播量约`115 g`（约`10.2 g/m²`）；拔节迹象出现即修剪顶端。[3]

#### 组合3（垄3：马齿苋 + 反枝苋）
- **前段马齿苋**：行距`0.22 m`（3行），株距`0.18 m`；种植密度约`25`株/m²，单段播量约`22 g`（约`2.0 g/m²`）；设置`10 cm`高围挡限制匍匐。[4]
- **后段反枝苋**：行距`0.25 m`（3行），株距`0.12 m`；种植密度约`33`株/m²，单段播量约`75 g`（约`6.7 g/m²`）；控制株高≤`5 cm`并保持叶面展开。[12]

#### 组合4（垄4：小飞蓬 + 灰菜）
- **前段小飞蓬**：行距`0.20 m`（4行），株距`0.14 m`；种植密度约`36`株/m²，单段播量约`65 g`（约`5.8 g/m²`），莲座期间苗至约`400`株。[13]
- **后段灰菜**：行距`0.25 m`（3行），株距`0.12 m`；种植密度约`33`株/m²，单段播量约`95 g`（约`8.4 g/m²`）；必要时薄剪顶部叶片保持可视度。

> 若需在双物种垄内增加第三条试验带，可在垄中央铺设`0.10 m`宽的黑色防草布，并沿布两侧布置低位定位桩，保证拍摄基准一致。[7]

### 6. 方案对比与选择建议

| 维度 | 方案一：全垄单物种 | 方案二：双物种同垄 | 管理提示 |
| --- | --- | --- | --- |
| 数据一致性 | 背景纯净、植株遮挡少，便于模型训练与参数对照。[7][8] | 图像更接近自然混生场景，可拓展模型泛化能力。[5][11] | 若首轮采集需建立基线，建议先采用方案一，再引入方案二增强多样性。 |
| 密度与播量 | 维持推荐密度即可；株高控制简单。[2][3] | 每物种播量需下调约20%，辅以隔离带与剪顶。[5][11] | 混播时实时记录两物种出苗差异，必要时错峰补播。 |
| 生长竞争 | 无杂草间竞争，管理工作量低。 | 存在光、水肥竞争，需增加巡查与局部调控。[12][13] | 建议在交界处预留缓冲带，定期翻检根系。 |
| 样本丰富度 | 每轮覆盖4个物种，需多轮才能完成全部名单。[7][8] | 单轮即可覆盖8个物种，数据多样性显著提升。[5][11] | 若采集周期有限，可优先使用方案二获取多物种样本。 |
| 设备协同 | 滑轨、补光等设备调校一次即可重复使用。 | 同垄不同物种需分段调光与调焦，摄影脚本更复杂。 | 可在方案二中预设拍摄脚本，或增加AI自动曝光。 |

> 综合建议：在模型冷启动或需精确衡量药效、株高控制时选择方案一；当目标转向提高训练数据多样性、模拟田间杂草互作时切换方案二。两方案可交替实施，以同一编码体系和日志模板保持数据可对比性。[5][7][8][11][12][13]

### 7. 设施识别周期作业节拍
- **周期第0周**：温室检修、消毒、铺滴灌；准备种源与标识物料。[1]
- **周期第1周**：播前浸种/催芽、建立小区标牌，完成摄影轨道或滑轨定位。
- **周期第2周**：播種或移栽，覆土≤`0.5 cm`，喷雾保湿。
- **周期第3周**：首次出苗调查，记录出苗率、株高、光照和湿度；试拍调参。
- **周期第4~6周**：按计划采集图像→剪顶→补播（如需）；记录每次操作时间与参数。
- **周期第7周**：结束轮次后清园、闷棚或蒸汽消毒7天，进入下一轮安排。

### 8. 日常执行要点
- 进棚前更换鞋套并在脚踏池消毒；作业工具按物种分区标记，防止交叉传播。
- 每日早晚巡查温湿度与株高，记录在Excel排程表中；一旦株高接近`5 cm`立即安排拍摄和剪顶。
- 拍摄后30分钟内完成剪顶及杂物清理，残体装袋焚烧或高温堆肥。
- 若需长时间补光，优先使用光谱一致的LED灯，并记录照度值供模型校正。

### 9. 图像数据采集与管理
- **采集窗口**：萌发后7~10天开始，每3~4天采集一次，直至株高接近`5 cm`；必要时在补播后错峰采集，丰富生育阶段样本。[7][8]
- **角度与光照**：每小区固定三个拍摄角度（俯视、斜视、侧视），使用灰度/色卡和尺标板（`30 cm × 30 cm`）置于画面固定位置。[7]
- **参数记录**：拍摄日志记录日期、时间、温湿度、光照强度、相机型号、镜头、曝光与增益设置；数据文件命名格式推荐`物种_垄号小区_轮次_时间戳_角度`。[8][9]
- **数据备份**：当日结束前上传至NAS或云端，保留RAW和压缩格式各一份；每轮次结束后进行元数据校验与样本质量评估。

### 10. 综合优势与风险控制
- **环境一致性**：固定垄宽与温室可控环境，使两种方案均处于低噪声条件，便于横向比较与模型复现。[1]
- **样本丰富度**：方案一通过多轮次覆盖全部物种，方案二在单轮内提供多物种混生数据，联合实施可快速构建不同组合的图像样本库。[7][8][10][11]
- **作业高效**：统一的“小区尺寸 + 编码规则”适用于两方案，便于排程、统计与自动化设备调用。
- **扩散风险控制**：剪顶、低氮和防草布等措施应用于两方案，可抑制种子逸散；混播段需额外巡查根系交缠情况。[2][3][5]
- **数据可追溯**：定位桩、色卡、日志与命名规范覆盖所有小区，方便将不同方案的数据统一存储与比对。[7][8][9]

### 11. 参考文献
[1] 中国科学院华南植物园. 《温室栽培指南》. https://scbg.cas.cn/old/ylyy/yyzp/201010/t20101002_2977855.html 访问日期：2025-11-04。
[2] 中国水稻研究所. 《稻田恶性杂草研究介绍》. https://cnrri.caas.cn/bsgk/xksz/dzjzyjyfzzx/276724.htm 访问日期：2025-11-04。
[3] 上海市农业技术推广服务中心. 《稻田杂草化学防除技术意见》. https://nyncw.sh.gov.cn/bcycyb/20180719/0009-76196.html 访问日期：2025-11-04。
[4] 全国农技推广中心. 《稻田杂草防控策略》. https://www.gzstv.com/a/3937d72bd2d24e60b3f8b9435d838178 访问日期：2025-11-04。
[5] 中华人民共和国农业农村部. 《国产化连栋温室智慧种植模式》. https://www.moa.gov.cn/ztzl/zhnyzxd/dfsj/202505/t20250512_6473867.htm 访问日期：2025-11-04。
[7] Milioto A, et al. "WeedMap: A Large-Scale Semantic Weed Mapping Framework using UAV Imagery." arXiv:1808.00100.
[8] Olsen A, et al. "DeepWeeds: A Multiclass Weed Species Image Dataset for Deep Learning." arXiv:1810.05726.
[9] Partel V, et al. "A Rapidly Deployable Classification System using Visual Data for Precision Weed Management." arXiv:1801.08613.
[10] Di Monte S. "A Random Planting Model." arXiv:2409.16432.
[11] 玉溪市农业农村局. 《香附子规模化种植技术要点》. https://m.yuxi.gov.cn/u/cms/yxszfxxgk/202401/18172458ypq5.pdf 访问日期：2025-11-04。
[12] 王勇, 等. 《珠三角地区四季草坪杂草群落组成及其生态位》. 生态学报, 2013. https://www.cje.net.cn/CN/abstract/abstract16493.shtml 访问日期：2025-11-04。
[13] 王敏, 等. 《川东北乡村不同生境中杂草多样性研究》. 四川农业大学学报, 2019. https://html.rhhz.net/STYNCHJXB/html/2019/11/20191108.htm 访问日期：2025-11-04。

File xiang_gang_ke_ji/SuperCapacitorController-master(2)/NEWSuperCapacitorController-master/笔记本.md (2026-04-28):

# *2024 超电重写*

## 4/19

IA测量不准确,用下载器供电,和电源箱供电,明明没有电流但是会有很大的电流测量出来,即使拟合了,每次上电测量值都不同,今天拿示波器测量的时候,因为不太会示波器(补一下[示波器笔记](https://evil0knight.github.io/quartz/%E6%9C%AF%E4%B8%AD%E8%87%AA%E6%9C%89%E4%B8%87%E9%92%9F%E7%B2%9F/%E7%A4%BA%E6%B3%A2%E5%99%A8),里面记录了烧了的原因),把芯片烧了,不过,正好把整个板子重新焊一边,

补一下之前几天遇到的问题,当时IA测量虽然不准但是还是能用的,是可以充放电的,但是到了电容充满的时候,会突然反灌电压,当时把电源电压抬到30v

还有一个情况是电源电压18往上,电容电压会被直接抬到33V

我认为这两者都是因为IA不准导致的,采样电阻是2mr的,适合大电流,对于小电流精度太低了,可是很奇怪的是IB是准的,所以我再猜是芯片有问题,所以这次芯片烧了正好把整个板子重新焊
[A端拟合数据](A 端电流拟合数据.xlsx)

还有一个焊接的细节,因为焊锡丝熔点不同,导致了焊接的困难,焊锡融化不了,使用小风热风枪吹下来,然后把锡拿吸锡带吸走

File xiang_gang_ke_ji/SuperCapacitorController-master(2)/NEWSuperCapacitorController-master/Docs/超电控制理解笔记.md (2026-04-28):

# 超电控制理解笔记

## 1. 当前总目标

### 1.2 系统在干什么

- 负载较小时：
- 负载较大时：
- 缓冲能量不足时：
- 电容电压过高时：

### 3.1 裁判/电池侧相关

- `refereePowerLimit`：
- `energyRemain`：
- `baseRefereePower`：
- `targetRefereePower`：
- `pReferee`：

### 3.2 超电/DC-DC相关

- `targetAPower`：
- `targetIA`：
- `iASide`：
- `vASide`：
- `vBSide`：
- `pBSide`：

### 3.3 最容易混淆的地方

- `baseRefereePower` 不是：
- `targetRefereePower` 不是：
- `pReferee` 更接近：
- `pBSide` 更接近：

## 4. 典型工况怎么理解

### 4.1 负载突然变大

- 观测到什么量变化：
- 哪个环先起作用：
- PWM 为什么会变：
- 超电是在充电还是放电：

### 4.2 负载较小

- 观测到什么量变化：
- 功率环会怎么调：
- 超电是在充电还是放电：

### 4.3 能量缓冲不足

- 代码位置：
- 当前看到的逻辑：
- 这代表“目标变成 10W”的是哪一路功率：
- 这不等于：
- 我自己的疑问：

### 4.4 电容电压过高

- 哪个环介入：
- 它是不是主串级环：
- 它更像限制还是主控制目标：

## 5. 关键问题记录

### 5.1 已确认

### 5.2 暂时不确定

### 5.3 之后要继续看代码确认

- `pReferee` 的具体计算式
- `pASide / pBSide` 的正负号定义
- A->B 和 B->A 时各变量物理意义
- `targetAPower` 的正负分别代表什么

## 6. 可直接补的结论草稿

### 6.1 整个超电就是想……

- 整个超电系统的核心，是通过双向 DC/DC 调节超电和底盘母线之间的功率流，让裁判/电池侧看到的功率尽量跟随一个动态目标。

### 6.2 为什么要多层环

- 功率不能直接靠 PWM 稳定执行，所以外层先决定“该给多少功率”，内层再用电流环把目标真正打到硬件上。

### 6.3 低缓冲时在干什么

- 当前代码表现为把裁判侧目标功率压到较低值，而不是简单写成“禁止使用超电”。

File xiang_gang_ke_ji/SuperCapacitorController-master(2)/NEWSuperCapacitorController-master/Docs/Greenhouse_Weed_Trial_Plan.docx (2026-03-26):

## 温室杂草识别试验方案（全垄布置）

### 1. 项目目标与地块概况

- 目标定位：在全封闭温室内建立四条标准垄的杂草识别样地，专门采集低株高（≤5 cm）阶段的图像数据，同时保留托盘或边沟小区作种源补充。[2][3][4][7][8]
- 地块结构：每条垄宽0.50 m、长45.0 m（面积22.5 m²），共四垄，总面积90 m²；垄间设置0.30 m巡查通道并铺防草布，垄尾保留1.0 m × 1.0 m缓冲区用于设备调头与物资堆放。
- 小区划分：每条垄沿长度方向划分为A/B/C三个连续小区，每小区长15.0 m、宽0.50 m，面积7.5 m²。A/B/C用于重复采样或不同处理（如光照、补光、控水差异）。
- 识别优先原则：四条垄全部用于识别样本采集，种源补育安排在垄尾托盘或另设基质槽，与主试验区完全隔离，避免影响拍摄。

### 2. 温室环境与通用管理

- 温度与湿度：白天维持16~18℃、夜间10~12℃，相对湿度60~70%；必要时开启顶部通风与侧膜，防止徒长。[1]
- 光照：保持棚膜洁净，阴天或冬季可补充LED顶光；如需遮阳，优先在轨道上方设置局部遮光布，保证拍摄光均匀。[1]
- 水肥策略：播后7天内保持基质湿润，使用清水滴灌或喷雾；识别阶段停用氮肥，仅补充低浓度（≤0.5 g/L）平衡营养液，控制株高≤5 cm。[2][3]
- 防扩散措施：四周加设20 cm深阻根膜，入棚设双门和脚踏消毒池；剪下的植株集中密封处理，防止种子逸散。[2][3]

### 3. 全垄识别布局原则

- 小区编号：记为“垄号-小区”（例：L1-A），结合物种名称和轮次建立编码（例：L1-A-CYP-01）。
- 播种策略：根据物种播幅在小区内布设2~4行，保证叶片铺满但不重叠；所有播量以下述小区面积（15.0 m × 0.50 m）为计算基准。
- 托盘补植：每个物种额外准备2~4个60 cm × 40 cm × 10 cm基质托盘，放置在垄尾缓冲区，用于补播或备份。

### 4. 方案一：全垄单物种识别布置

轮次之间建议预留1周清园与闷棚时间，保证下一批次无残根残茎干扰。所有小区均保持单物种，便于精确控制密度、株高与背景。[2][3][7]

#### 轮次1（周期0~6周）：香附子 / 稗草 / 牛筋草 / 马唐

- 垄1 香附子：
  - 小区尺寸：A/B/C各0.50 m × 15.0 m。
  - 栽植密度：行距0.18 m（3行），穴距0.18 m，每穴1块茎。
  - 种植密度：约31穴/m²；单小区约230穴，整垄约690穴。
  - 管理要点：覆土厚度3 cm，萌芽后保持株高≤5 cm，必要时摘除顶部叶片。[2]
- 垄2 稗草：
  - 小区尺寸：A/B/C各0.50 m × 15.0 m。
  - 播种密度：行距0.15 m（4行），株距0.05 m。
  - 种植密度：约133株/m²；单小区播量约110 g（约14.7 g/m²），整垄约330 g。
  - 管理要点：保持2~3叶期拍摄，喷雾补水避免地表板结。[3]
- 垄3 牛筋草：
  - 小区尺寸：A/B/C各0.50 m × 15.0 m。
  - 播种密度：行距0.20 m（3行），株距0.08 m。
  - 种植密度：约63株/m²；单小区播量约70 g（约9.3 g/m²），整垄约210 g。
  - 管理要点：分蘖超过3株时剪除侧蘖，保持叶片舒展。
- 垄4 马唐：
  - 小区尺寸：A/B/C各0.50 m × 15.0 m。
  - 播种密度：行距0.20 m（3行），株距0.06 m。
  - 种植密度：约83株/m²；单小区播量约80 g（约10.7 g/m²），整垄约240 g。
  - 管理要点：拔节迹象出现即剪顶，结合补光获取均匀图像。[3]

#### 轮次2（周期7~12周）：马齿苋 / 反枝苋 / 小飞蓬 / 灰菜

- 垄1 马齿苋：3行布局，行距0.20 m，株距0.15 m；种植密度约33株/m²，单小区约250株（整垄750株）；围设高度10 cm的PVC挡板防匍匐。
- 垄2 反枝苋：3行，行距0.25 m，株距0.10 m；种植密度约40株/m²，单小区播量50 g（约6.7 g/m²，整垄150 g）；控水控肥使株高≤5 cm。[4]
- 垄3 小飞蓬：4行，行距0.18 m，莲座株距0.12 m；种植密度约46株/m²，单小区播量40 g（约5.3 g/m²，整垄120 g），间苗至每小区约200株。
- 垄4 灰菜：3行，行距0.25 m，株距0.10 m；种植密度约40株/m²，单小区播量60 g（约8.0 g/m²，整垄180 g）；保持植株直立，必要时轻度间苗。

#### 轮次3（周期13~18周）：龙葵 / 酸模叶蓼 / 狗尾巴草 / 蒲公英+车前

- 垄1 龙葵：2行，行距0.25 m，穴距0.20 m；种植密度约20株/m²，单小区移栽苗约60株（整垄180株）；控温控氮保持株高≤5 cm，果实初显即剪除。[3]
- 垄2 酸模叶蓼：3行，行距0.30 m，株距0.15 m；种植密度约22株/m²，单小区播量45 g（约6.0 g/m²，整垄135 g）；滴灌带两侧对称布置增强画面整齐度。
- 垄3 狗尾巴草：4行，行距0.15 m，株距0.10 m；种植密度约67株/m²，单小区播量60 g（约8.0 g/m²，整垄180 g）；通过降温和剪顶将株高控制在5 cm以内。
- 垄4 蒲公英+车前：各物种分配A/B/C小区的半幅（每物种面积0.50 m × 7.5 m），莲座密度0.30 m × 0.20 m；种植密度约17株/m²，单物种小区约60株，整垄约180株；抽薹即刻剪除。

#### 轮次4（周期19~24周）：附地菜 / 益母草 / 草木犀 / 野豌豆

- 垄1 附地菜群落：4行，行距0.20 m，株距0.10 m；种植密度约50株/m²，单小区播量35 g（约4.7 g/m²，整垄105 g）；保持莲座状态。
- 垄2 益母草：3行，行距0.25 m，株距0.12 m；种植密度约33株/m²，单小区播量40 g（约5.3 g/m²，整垄120 g）；株高接近5 cm即采集。
- 垄3 草木犀：3行，行距0.30 m，株距0.15 m；种植密度约22株/m²，单小区播量45 g（约6.0 g/m²，整垄135 g）；低位绳网限制藤蔓高度。
- 垄4 野豌豆：3行，行距0.30 m，株距0.15 m；种植密度约22株/m²，单小区播量50 g（约6.7 g/m²，整垄150 g）；设置低位绑蔓点保持苗期姿态。

### 5. 方案二：双物种同垄识别布置

依据设施混播管理资料，双物种条带或分段种植可提升数据多样性，但需增加隔离带与密度衰减，避免相互遮蔽。[5][11][12][13]

组合搭配依据

设施温室混播建议：农业农村部智慧种植模式强调可通过条带化或分段混播提升空间利用效率与数据多样性，但需设置隔离带并调低播量，避免相互遮蔽。[5]

块茎杂草与禾本科共管：香附子技术要点指出在高湿基质中可与禾本科共享水肥管理，只需降低禾本科播量并留出观测空间，因此组合1选择香附子+稗草并下调稗草密度。[3][11]

禾本科密植控制：稗草、牛筋草、马唐等一年生禾本科在密植条件下会相互遮挡，推广意见建议间苗或降低播量，组合2据此分段种植并下调播量以保持株高≤5 cm。[3]

阔叶杂草共生生态：研究表明马齿苋、反枝苋、小飞蓬、灰菜等阔叶杂草常在同一生境共存，但需控制密度和高度，组合3与组合4依靠分段、剪顶和围挡保持叶片清晰度。[12][13]

识别数据多样性：遥感与图像识别研究（WeedMap、DeepWeeds）显示多物种共存样本能提升模型泛化能力，但需维持单株轮廓清晰，因此方案二在保持株高≤5 cm的前提下采用条带隔离与密度衰减，兼顾可视性与多样性。[7][8]

分区方式：每条垄仍宽0.50 m、长45.0 m，沿长度划分为前段（0~22.5 m）与后段（22.5~45 m）两个亚小区，各面积11.25 m²。

隔离带：在两亚小区交界设置0.5 m宽防草布缓冲，或铺设可移动PVC板，减少根系互侵与影像干扰。

播种原则：同垄内优先搭配1种禾本科+1种阔叶，或块茎+实生型，通过下调单物种播量20%降低竞争。[5][11]

#### 组合1（垄1：香附子 + 稗草）

- 前段（0~22.5 m）香附子：行距0.18 m（3行），穴距0.20 m，每穴1块茎；种植密度约28穴/m²，单段约320穴，总播块茎320~330粒。[11]
- 后段（22.5~45 m）稗草：行距0.18 m（3行），株距0.06 m；种植密度约93株/m²，单段播量约150 g（约13.3 g/m²）；通过间苗维持株高≤5 cm。[3]

#### 组合2（垄2：牛筋草 + 马唐）

- 前段牛筋草：行距0.22 m（3行），株距0.10 m；种植密度约45株/m²，单段播量约100 g（约8.9 g/m²）；出苗后剪除多余分蘖。[3]
- 后段马唐：行距0.22 m（3行），株距0.08 m；种植密度约57株/m²，单段播量约115 g（约10.2 g/m²）；拔节迹象出现即修剪顶端。[3]

#### 组合3（垄3：马齿苋 + 反枝苋）

- 前段马齿苋：行距0.22 m（3行），株距0.18 m；种植密度约25株/m²，单段播量约22 g（约2.0 g/m²）；设置10 cm高围挡限制匍匐。[4]
- 后段反枝苋：行距0.25 m（3行），株距0.12 m；种植密度约33株/m²，单段播量约75 g（约6.7 g/m²）；控制株高≤5 cm并保持叶面展开。[12]

#### 组合4（垄4：小飞蓬 + 灰菜）

- 前段小飞蓬：行距0.20 m（4行），株距0.14 m；种植密度约36株/m²，单段播量约65 g（约5.8 g/m²），莲座期间苗至约400株。[13]
- 后段灰菜：行距0.25 m（3行），株距0.12 m；种植密度约33株/m²，单段播量约95 g（约8.4 g/m²）；必要时薄剪顶部叶片保持可视度。

若需在双物种垄内增加第三条试验带，可在垄中央铺设0.10 m宽的黑色防草布，并沿布两侧布置低位定位桩，保证拍摄基准一致。[7]

### 6. 方案对比与选择建议

维度 | 方案一：全垄单物种 | 方案二：双物种同垄 | 管理提示
数据一致性 | 背景纯净、植株遮挡少，便于模型训练与参数对照。[7][8] | 图像更接近自然混生场景，可拓展模型泛化能力。[5][11] | 若首轮采集需建立基线，建议先采用方案一，再引入方案二增强多样性。
密度与播量 | 维持推荐密度即可；株高控制简单。[2][3] | 每物种播量需下调约20%，辅以隔离带与剪顶。[5][11] | 混播时实时记录两物种出苗差异，必要时错峰补播。
生长竞争 | 无杂草间竞争，管理工作量低。 | 存在光、水肥竞争，需增加巡查与局部调控。[12][13] | 建议在交界处预留缓冲带，定期翻检根系。
样本丰富度 | 每轮覆盖4个物种，需多轮才能完成全部名单。[7][8] | 单轮即可覆盖8个物种，数据多样性显著提升。[5][11] | 若采集周期有限，可优先使用方案二获取多物种样本。
设备协同 | 滑轨、补光等设备调校一次即可重复使用。 | 同垄不同物种需分段调光与调焦，摄影脚本更复杂。 | 可在方案二中预设拍摄脚本，或增加AI自动曝光。

综合建议：在模型冷启动或需精确衡量药效、株高控制时选择方案一；当目标转向提高训练数据多样性、模拟田间杂草互作时切换方案二。两方案可交替实施，以同一编码体系和日志模板保持数据可对比性。[5][7][8][11][12][13]

### 7. 设施识别周期作业节拍

- 周期第0周：温室检修、消毒、铺滴灌；准备种源与标识物料。[1]
- 周期第1周：播前浸种/催芽、建立小区标牌，完成摄影轨道或滑轨定位。
- 周期第2周：播種或移栽，覆土≤0.5 cm，喷雾保湿。
- 周期第3周：首次出苗调查，记录出苗率、株高、光照和湿度；试拍调参。
- 周期第4~6周：按计划采集图像→剪顶→补播（如需）；记录每次操作时间与参数。
- 周期第7周：结束轮次后清园、闷棚或蒸汽消毒7天，进入下一轮安排。

### 8. 日常执行要点

- 进棚前更换鞋套并在脚踏池消毒；作业工具按物种分区标记，防止交叉传播。
- 每日早晚巡查温湿度与株高，记录在Excel排程表中；一旦株高接近5 cm立即安排拍摄和剪顶。
- 拍摄后30分钟内完成剪顶及杂物清理，残体装袋焚烧或高温堆肥。
- 若需长时间补光，优先使用光谱一致的LED灯，并记录照度值供模型校正。

### 9. 图像数据采集与管理

- 采集窗口：萌发后710天开始，每34天采集一次，直至株高接近5 cm；必要时在补播后错峰采集，丰富生育阶段样本。[7][8]
- 角度与光照：每小区固定三个拍摄角度（俯视、斜视、侧视），使用灰度/色卡和尺标板（30 cm × 30 cm）置于画面固定位置。[7]
- 参数记录：拍摄日志记录日期、时间、温湿度、光照强度、相机型号、镜头、曝光与增益设置；数据文件命名格式推荐物种_垄号小区_轮次_时间戳_角度。[8][9]
- 数据备份：当日结束前上传至NAS或云端，保留RAW和压缩格式各一份；每轮次结束后进行元数据校验与样本质量评估。

### 10. 综合优势与风险控制

- 环境一致性：固定垄宽与温室可控环境，使两种方案均处于低噪声条件，便于横向比较与模型复现。[1]
- 样本丰富度：方案一通过多轮次覆盖全部物种，方案二在单轮内提供多物种混生数据，联合实施可快速构建不同组合的图像样本库。[7][8][10][11]
- 作业高效：统一的“小区尺寸 + 编码规则”适用于两方案，便于排程、统计与自动化设备调用。
- 扩散风险控制：剪顶、低氮和防草布等措施应用于两方案，可抑制种子逸散；混播段需额外巡查根系交缠情况。[2][3][5]
- 数据可追溯：定位桩、色卡、日志与命名规范覆盖所有小区，方便将不同方案的数据统一存储与比对。[7][8][9]

### 11. 参考文献

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

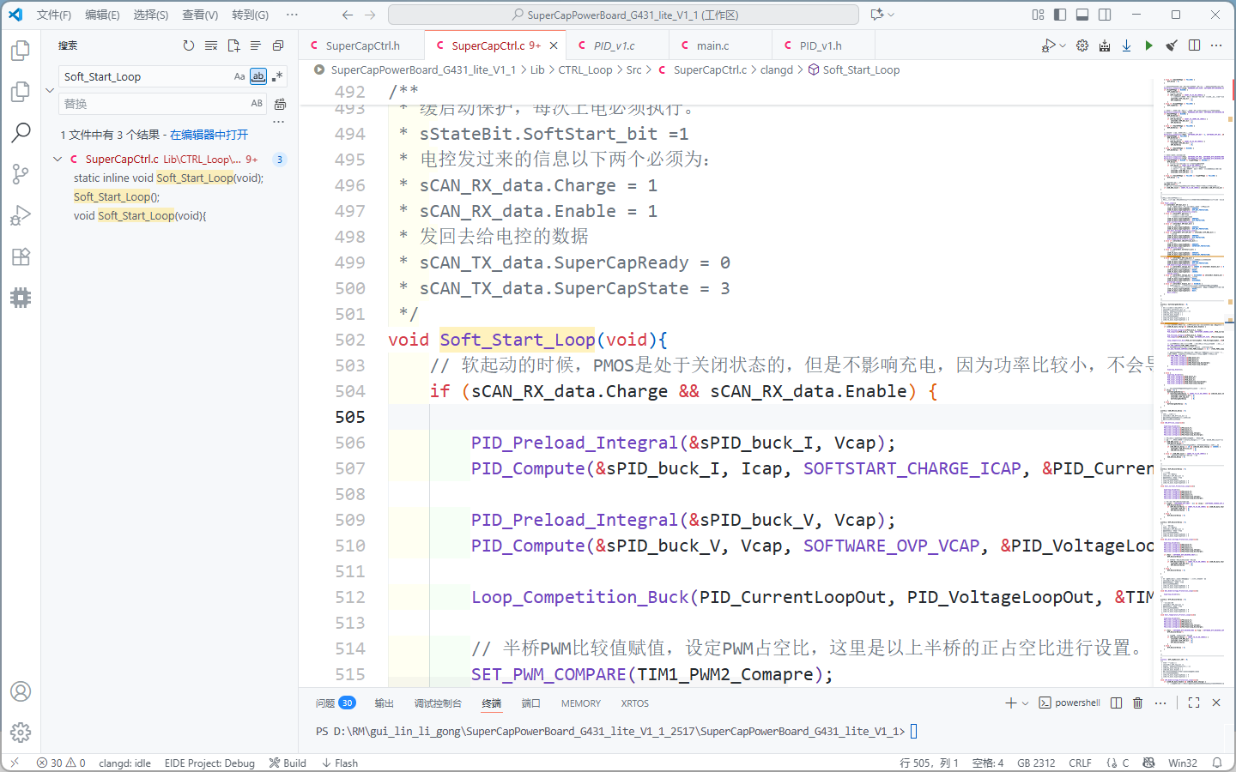
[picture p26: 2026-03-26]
gui_lin_li_gong/RM_SUPERCAP_JSU-main/RM_SUPERCAP_JSU-main/image/4af9171b36c758007bd921bbe818e17b.png

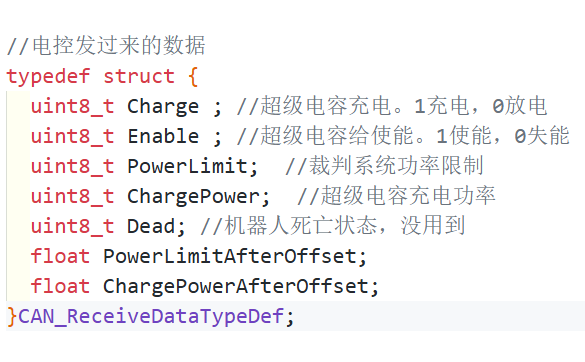
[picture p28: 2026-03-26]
gui_lin_li_gong/RM_SUPERCAP_JSU-main/RM_SUPERCAP_JSU-main/image/6200439e373334d2f63a813156c07891.png

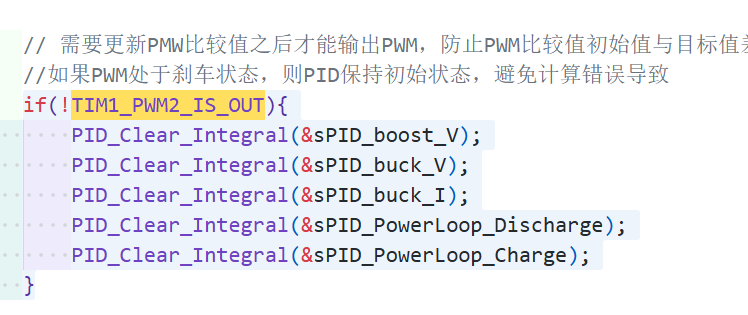
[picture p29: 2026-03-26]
gui_lin_li_gong/RM_SUPERCAP_JSU-main/RM_SUPERCAP_JSU-main/image/fabafc9a1ea7090c792672b683ed3a64.png

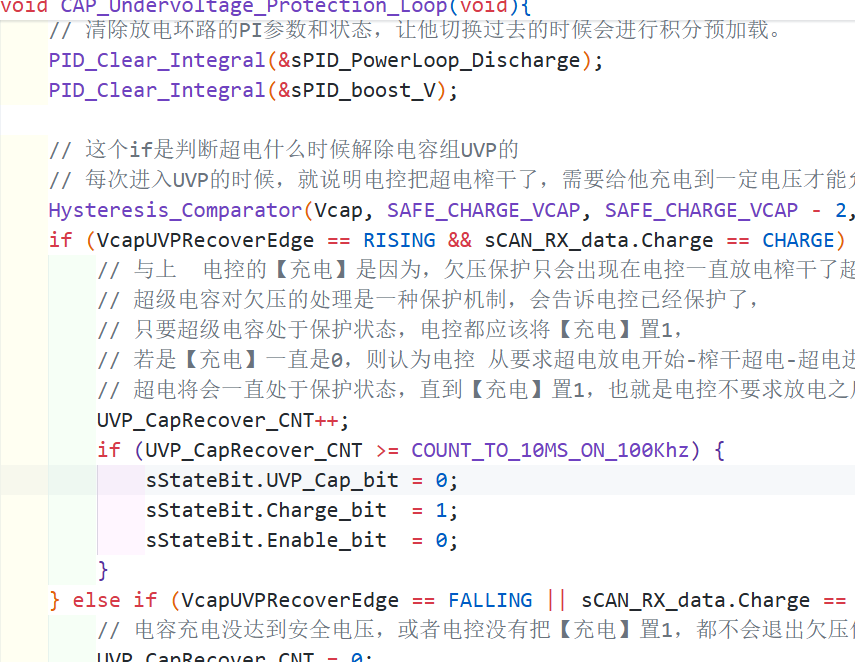
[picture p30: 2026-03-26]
gui_lin_li_gong/RM_SUPERCAP_JSU-main/RM_SUPERCAP_JSU-main/image/4f95a043e1c274b82a52535207094248.png

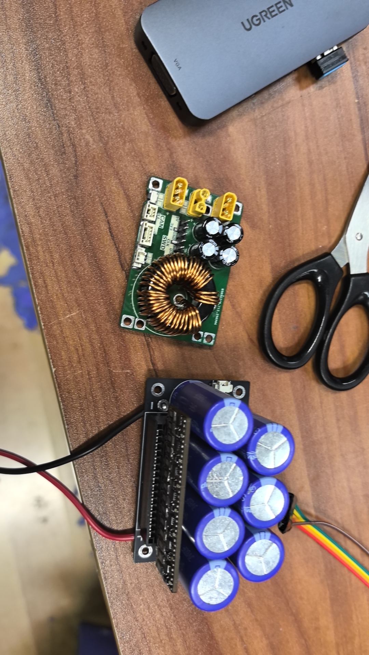
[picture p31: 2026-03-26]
gui_lin_li_gong/RM_SUPERCAP_JSU-main/RM_SUPERCAP_JSU-main/image/wx_camera_1759242208115.jpg

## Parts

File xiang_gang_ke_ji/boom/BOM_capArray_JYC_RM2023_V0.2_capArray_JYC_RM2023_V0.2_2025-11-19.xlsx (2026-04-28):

No. | Quantity | Comment | Designator | Footprint | Value | Manufacturer Part | Manufacturer | Supplier Part | Supplier | JLCPCB Price | JLCPCB Stock
1 | 10 | 50F | C1,C2,C3,C4,C5,C6,C7,C8,C9,C10 | Capacitor_THT:CP_Radial_D18.0mm_P7.50mm
2 | 1 | 50F | C11 | Capacitor_THT:CP_Radial_D18.0mm_P7.50mm | 50F
3 | 1 | 2200uf | C12 | Capacitor_THT:CP_Radial_D18.0mm_P7.50mm
4 | 11 | LED | D1,D2,D3,D4,D5,D6,D7,D8,D9,D10,D11 | LED_SMD:LED_0603_1608Metric
5 | 1 | LED | D12 | LED_SMD:LED_0603_1608Metric | LED
6 | 1 | SMCJ30A | D13 | Diode_SMD:D_SMC | SMCJ30A
7 | 1 | MountingHole_Pad | H1 | MountingHole:MountingHole_2.2mm_M2_Pad_Via
8 | 1 | MountingHole_Pad | H2 | MountingHole:MountingHole_2.2mm_M2_Pad_Via | MountingHole_Pad
9 | 1 | MountingHole_Pad | H3 | MountingHole:MountingHole_3.2mm_M3_Pad_Via | MountingHole_Pad
10 | 3 | MountingHole_Pad | H4,H5,H6 | MountingHole:MountingHole_3.2mm_M3_Pad_Via
11 | 10 | Q_NMOS_GDS | Q1,Q3,Q4,Q5,Q6,Q7,Q8,Q9,Q10,Q11 | Package_TO_SOT_SMD:TO-252-2
12 | 1 | Q_NMOS_GDS | Q2 | Package_TO_SOT_SMD:TO-252-2 | Q_NMOS_GDS
13 | 32 | 1k | R1,R2,R3,R4,R8,R9,R10,R14,R15,R16,R20,R21,R22,R23,R24,R25,R26,R27,R28,R29,R30,R31,R37,R46,R47,R48,R53,R54,R55,R57,R58,R59 | Resistor_SMD:R_0603_1608Metric
14 | 32 | R300 | R5,R6,R7,R11,R12,R13,R17,R18,R19,R33,R34,R35,R36,R38,R39,R40,R42,R43,R44,R45,R49,R50,R51,R61,R62,R63,R65,R66,R67,R69,R70,R71 | Resistor_SMD:R_2512_6332Metric_Pad1.40x3.35mm_HandSolder
15 | 1 | 1k | R32 | Resistor_SMD:R_0603_1608Metric | 1k
16 | 1 | R300 | R41 | Resistor_SMD:R_2512_6332Metric_Pad1.40x3.35mm_HandSolder | R300
17 | 1 | 5.1k | R52 | Resistor_SMD:R_0603_1608Metric
18 | 10 | ~ | U1,U2,U3,U4,U5,U6,U7,U8,U9,U10 | Package_TO_SOT_SMD:SOT-23-5
19 | 1 | ~ | U11 | Package_TO_SOT_SMD:SOT-23-5 | ~

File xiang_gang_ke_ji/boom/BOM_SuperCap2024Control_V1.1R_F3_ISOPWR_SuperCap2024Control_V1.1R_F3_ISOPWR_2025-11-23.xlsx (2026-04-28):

No. | Quantity | Comment | Designator | Footprint | Value | Manufacturer Part | Manufacturer | Supplier Part | Supplier | JLCPCB Price | JLCPCB Stock
1 | 1 | Device_Buzzer | BZ1 | 0_RM2024:MLT-9032 | Buzzer-9032
2 | 26 | Device_C | C1,C8,C10,C11,C12,C13,C14,C17,C19,C20,C21,C22,C23,C24,C25,C26,C27,C28,C29,C30,C31,C32,C33,C39,C41,C47 | Capacitor_SMD:C_0603_1608Metric | 100n
3 | 3 | Device_C_Polarized | C2,C6,C7 |  | C_Polarized
4 | 7 | Device_C | C3,C5,C15,C16,C34,C40,C42 | Capacitor_SMD:C_0603_1608Metric | 10u
5 | 1 | Device_C | C4 | Capacitor_SMD:C_0603_1608Metric | 20p
6 | 12 | Device_C | C9,C18,C36,C37,C44,C45,C49,C50,C52,C53,C54,C55 | Capacitor_SMD:C_1206_3216Metric | 10u
7 | 2 | Device_C | C35,C48 | Capacitor_SMD:C_0603_1608Metric | 100p
8 | 2 | Device_C_Polarized | C38,C46 | Capacitor_Tantalum_SMD:CP_EIA-6032-28_Kemet-C | C_Polarized
9 | 1 | Device_C | C43 | Capacitor_SMD:C_0603_1608Metric | 10n
10 | 4 | Device_C | C51,C56,C57,C58 | Capacitor_SMD:C_1206_3216Metric | 100u 6.3V
11 | 3 | Device_D_Schottky | D1,D2,D3 | Diode_SMD:D_SMF | DSS34
12 | 1 | Diode_SMF5V0A | D4 | Diode_SMD:D_SMF | SMF3.3A
13 | 1 | Diode_SMAJ28A | D5 | Diode_SMD:D_SMA | SMAJ28A
14 | 6 | Device_LED | D6,D7,D8,D9,D13,D14 | LED_SMD:LED_0603_1608Metric | LED
15 | 3 | Diode_SMF10A | D10,D11,D19 | Diode_SMD:D_SMF | SMF10A
16 | 1 | Diode_SMF5V0A | D22 | Diode_SMD:D_SMF | SMF5V0A
17 | 2 | Device_Fuse | F1,F2 | Fuse:Fuse_1206_3216Metric | 30A
18 | 2 | Device_Polyfuse | F3,F4 | Fuse:Fuse_1206_3216Metric | 1A
19 | 1 | Device_FerriteBead | FB1 | Inductor_SMD:L_1206_3216Metric | FerriteBead
20 | 1 | Device_FerriteBead | FB2 | Inductor_SMD:L_0603_1608Metric | FerriteBead
21 | 3 | Mechanical_MountingHole_Pad | H1,H2,H3 | MountingHole:MountingHole_3.2mm_M3_ISO14580_Pad | MountingHole_Pad
22 | 2 | Connector_Generic_Conn_02x02_Odd_Even | J1,J4 | Connector_PinHeader_2.54mm:PinHeader_2x02_P2.54mm_Vertical_SMD | Conn_02x02_Odd_Even
23 | 1 | Connector_Generic_MountingPin_Conn_01x02_MountingPin | J2 | Connector_JST:JST_GH_SM02B-GHS-TB_1x02-1MP_P1.25mm_Horizontal | GH1.25_2P_Vertical
24 | 1 | Connector_Generic_MountingPin_Conn_01x04_MountingPin | J3 | Connector_Molex:Molex_PicoBlade_53261-0471_1x04-1MP_P1.25mm_Horizontal | PicoBlade_1.25_4P
25 | 2 | Connector_Generic_Conn_02x02_Odd_Even | J5,J6 | Connector_PinHeader_2.54mm:PinHeader_2x02_P2.54mm_Vertical | Conn_02x02_Odd_Even
26 | 1 | Device_L | L1 | Inductor_SMD:L_Bourns-SRN4018 | 4.7u
27 | 1 | Device_L | L2 | Inductor_SMD:L_Sunlord_SWPA252012S | 4.7u
28 | 1 | Transistor_FET_AO3400A | Q1 | Package_TO_SOT_SMD:SOT-23 | AO3400A
29 | 11 | Device_R | R1,R2,R3,R4,R5,R22,R23,R24,R26,R27,R37 | Resistor_SMD:R_0603_1608Metric | 33r
30 | 4 | Device_R | R6,R28,R40,R42 | Resistor_SMD:R_0603_1608Metric | 10k
31 | 4 | Device_R | R7,R8,R10,R11 | Resistor_SMD:R_0603_1608Metric | 2.2k
32 | 3 | Device_R_US | R9,R12,R15 | Resistor_SMD:R_2512_6332Metric | 2mr
33 | 4 | Device_R | R13,R14,R30,R31 | Resistor_SMD:R_0603_1608Metric | 1k
34 | 2 | Device_R | R16,R19 | Resistor_SMD:R_0603_1608Metric | 90k 25ppm
35 | 2 | Device_R | R17,R20 | Resistor_SMD:R_0603_1608Metric | 10k 25ppm
36 | 2 | Device_R | R18,R21 | Resistor_SMD:R_0603_1608Metric | 68r
37 | 3 | Device_R | R25,R36,R38 | Resistor_SMD:R_0603_1608Metric | 120r
38 | 1 | Device_R | R39 | Resistor_SMD:R_0603_1608Metric | 118k
39 | 1 | Device_R | R41 | Resistor_SMD:R_0603_1608Metric | 53.6k
40 | 6 | Connector_TestPoint | TP1,TP2,TP3,TP4,TP5,TP6 | TestPoint:TestPoint_Plated_Hole_D3.0mm | TestPoint
41 | 2 | 0_RM2023_ISO_DC | U1,U3 | 0_RM2024:BxxxxS-1W | ISO_DC
42 | 3 | Amplifier_Current_INA240A1PW | U2,U4,U5 | Package_SO:TSSOP-8_4.4x3mm_P0.65mm | INA240A1PW
43 | 1 | 0_RM2023_GS8332-SR | U6 | Package_SO:SOIC-8_3.9x4.9mm_P1.27mm | GS8332-SR
44 | 1 | MCU_ST_STM32F3_STM32F334R8Tx | U7 | Package_QFP:LQFP-64_10x10mm_P0.5mm | STM32F334R8Tx
45 | 1 | Interface_CAN_LIN_TJA1042T-3 | U8 | Package_SO:SOIC-8_3.9x4.9mm_P1.27mm | SIT1042/3
46 | 2 | 0_RM2023_SY8301 | U9,U11 | Package_TO_SOT_SMD:SOT-23-6 | RY8411
47 | 1 | 0_RM2023_RS3236 | U10 | Package_TO_SOT_SMD:SOT-23-5 | RS3236
48 | 1 | Device_Crystal_GND2_Small | Y1 | Crystal:Resonator_SMD_Murata_CSTxExxV-3Pin_3.0x1.1mm | CSTCE8M

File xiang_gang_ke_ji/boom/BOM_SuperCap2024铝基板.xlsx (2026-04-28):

No. | Quantity | Comment | Designator | Footprint | Value | Manufacturer Part | Manufacturer | Supplier Part | Supplier | JLCPCB Price | JLCPCB Stock
1 | 1 | 10u | C1 | Capacitor_SMD:C_0603_1608Metric
2 | 3 | 220u | C2,C5,C6 | Capacitor_SMD:CP_Elec_8x10
3 | 1 | 220u | C3 | Capacitor_SMD:CP_Elec_8x10 | 220u
4 | 5 | 10u | C4,C9,C10,C11,C14 | Capacitor_SMD:C_1206_3216Metric
5 | 2 | 100n | C7,C8 | Capacitor_SMD:C_0603_1608Metric
6 | 1 | 10u | C12 | Capacitor_SMD:C_1206_3216Metric | 10u
7 | 1 | 10u | C13 | Capacitor_SMD:C_0603_1608Metric | 10u
8 | 1 | TVS | D1 | Diode_SMD:D_SMC | SMCJ28A
9 | 1 | TVS | D2 | Diode_SMD:D_SMC
10 | 3 | SMF10A | D3,D4,D6 | Diode_SMD:D_SOD-123F
11 | 1 | SMF10A | D5 | Diode_SMD:D_SOD-123F | D_Schottky
12 | 1 | GND | H1 | TestPoint:TestPoint_Pad_D4.0mm
13 | 1 | MountingHole | H2 | MountingHole:MountingHole_3.2mm_M3 | MountingHole
14 | 1 | A | H3 | TestPoint:TestPoint_Pad_D4.0mm | GND
15 | 1 | B | H4 | TestPoint:TestPoint_Pad_D4.0mm
16 | 1 | MountingHole | H5 | MountingHole:MountingHole_3.2mm_M3
17 | 1 | Conn_02x02_Odd_Even | J1 | Connector_PinHeader_2.54mm:PinHeader_2x02_P2.54mm_Vertical_SMD | Conn_02x02_Odd_Even
18 | 3 | Conn_02x02_Odd_Even | J2,J3,J4 | Connector_PinHeader_2.54mm:PinHeader_2x02_P2.54mm_Vertical_SMD
19 | 1 | 10u 40A | L1 | 0_RM2024:PQ2617BHA | 10u 40A
20 | 1 | BSC070N10NS3G | Q1 | 0_RM2024_HandSolder:TDSON-8-1_HandSolder | BSC066N06
21 | 3 | BSC070N10NS3G | Q2,Q3,Q4 | 0_RM2024_HandSolder:TDSON-8-1_HandSolder
22 | 1 | 120r | R1 | Resistor_SMD:R_1206_3216Metric | 10k NTC
23 | 1 | 120r | R2 | Resistor_SMD:R_1206_3216Metric
24 | 3 | 3.3r | R3,R4,R6 | Resistor_SMD:R_0603_1608Metric
25 | 1 | 3.3r | R5 | Resistor_SMD:R_0603_1608Metric | 10k
26 | 4 | 10k | R7,R8,R9,R10 | Resistor_SMD:R_0603_1608Metric
27 | 1 | 10k NTC | TH1 | Resistor_SMD:R_1206_3216Metric
28 | 1 | UCC27201ADR | U1 | Package_SO:SOP-8_3.9x4.9mm_P1.27mm | UCC27201ADR
29 | 1 | UCC27201ADR | U2 | Package_SO:SOP-8_3.9x4.9mm_P1.27mm

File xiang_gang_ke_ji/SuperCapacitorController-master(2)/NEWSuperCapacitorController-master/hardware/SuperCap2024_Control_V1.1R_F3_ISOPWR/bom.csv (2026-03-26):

Designator | Footprint | Quantity | Value | LCSC Part #
BZ1 | MLT-9032 | 1 | Buzzer-9032
C1, C10, C11, C12, C13, C14, C17, C19, C20, C21, C22, C23, C24, C25, C26, C27, C28, C29, C30, C31, C32, C33, C39, C41, C47, C8 | 0603 | 26 | 100n
C15, C16, C3, C34, C40, C42, C5 | 0603 | 7 | 10u
C18, C36, C37, C44, C45, C49, C50, C52, C53, C54, C55, C9 | 1206 | 12 | 10u
C38, C46 | CP_EIA-6032-28_Kemet-C | 2 | C_Polarized
C4 | 0603 | 1 | 20p
C43 | 0603 | 1 | 10n
C51, C56, C57, C58 | 1206 | 4 | 100u 6.3V
D1, D2, D3 | D_SMF | 3 | DSS34
D10, D11, D19 | D_SMF | 3 | SMF10A
D13, D14, D6, D7, D8, D9 | 0603 | 6 | LED
D22 | D_SMF | 1 | SMF5V0A
D4 | D_SMF | 1 | SMF3.3A
D5 | D_SMA | 1 | SMAJ28A
F1, F2 | 1206 | 2 | 30A
F3, F4 | 1206 | 2 | 1A
FB1 | 1206 | 1 | FerriteBead
FB2 | 0603 | 1 | FerriteBead
H1, H2, H3 | MountingHole_3.2mm_M3_ISO14580_Pad | 3 | MountingHole_Pad
J1, J4 | PinHeader_2x02_P2.54mm_Vertical_SMD | 2 | Conn_02x02_Odd_Even
J2 | JST_GH_SM02B-GHS-TB_1x02-1MP_P1.25mm_Horizontal | 1 | Conn_01x02_MountingPin
J3 | Molex_PicoBlade_53261-0471_1x04-1MP_P1.25mm_Horizontal | 1 | Conn_01x04_MountingPin
J5, J6 | PinHeader_2x02_P2.54mm_Vertical | 2 | Conn_02x02_Odd_Even
L1 | L_Bourns-SRN4018 | 1 | 4.7u
L2 | L_Sunlord_SWPA252012S | 1 | 4.7u
Q1 | SOT-23 | 1 | AO3400A
R1, R2, R22, R23, R24, R26, R27, R3, R37, R4, R5 | 0603 | 11 | 33r
R10, R11, R7, R8 | 0603 | 4 | 2.2k
R12, R15, R9 | 2512 | 3 | 2mr
R13, R14, R30, R31 | 0603 | 4 | 1k
R16, R19 | 0603 | 2 | 90k 25ppm
R17, R20 | 0603 | 2 | 10k 25ppm
R18, R21 | 0603 | 2 | 68r
R25, R36, R38 | 0603 | 3 | 120r
R28, R40, R42, R6 | 0603 | 4 | 10k
R39 | 0603 | 1 | 118k
R41 | 0603 | 1 | 53.6k
TP1, TP2, TP3, TP4, TP5, TP6 | TestPoint_Plated_Hole_D3.0mm | 6 | TestPoint
U1, U3 | BxxxxS-1W | 2 | ISO_DC
U10 | SOT-23-5 | 1 | RS3236
U11, U9 | SOT-23-6 | 2 | RY8411
U2, U4, U5 | TSSOP-8_4.4x3mm_P0.65mm | 3 | INA240A1PW
U6 | SOIC-8_3.9x4.9mm_P1.27mm | 1 | GS8332-SR
U7 | LQFP-64_10x10mm_P0.5mm | 1 | STM32F334R8Tx
U8 | SOIC-8_3.9x4.9mm_P1.27mm | 1 | SIT1042/3
Y1 | Resonator_SMD_Murata_CSTxExxV-3Pin_3.0x1.1mm | 1 | CSTCE8M

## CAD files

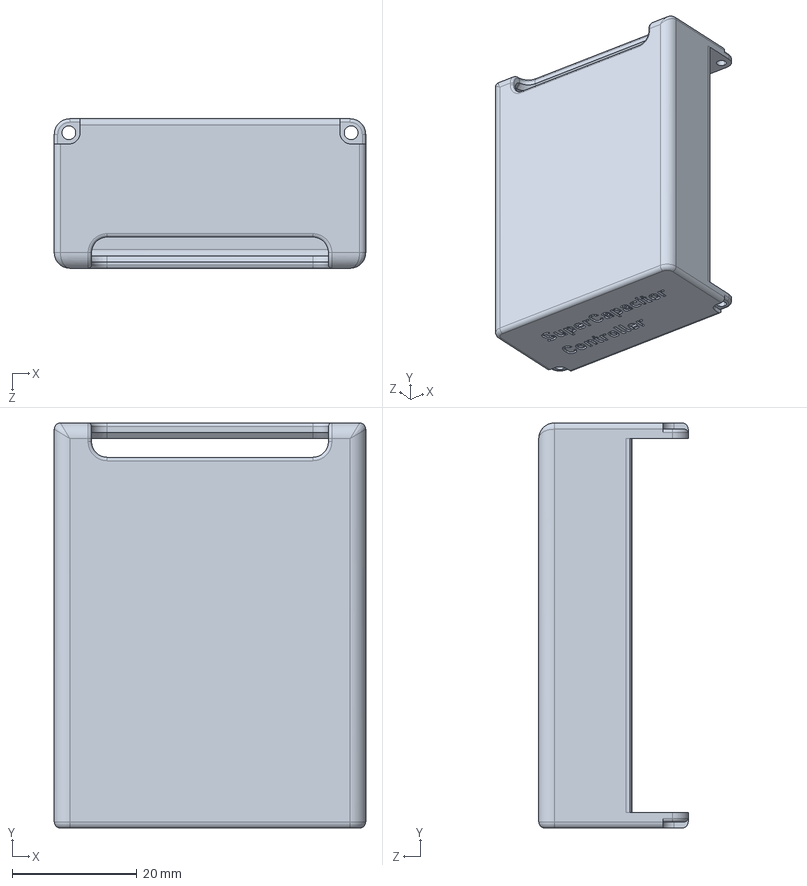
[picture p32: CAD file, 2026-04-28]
xiang_gang_ke_ji/24电容上壳.STEP
50.0 x 65.0 x 24.0 mm

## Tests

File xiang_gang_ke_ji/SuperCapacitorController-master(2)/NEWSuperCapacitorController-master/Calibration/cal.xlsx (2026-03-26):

 | real data |  | adc value |  | k | b
VASide | 12 | 24 | 1483 | 2969 | 0.008075370121 | 0.02422611036
VBSide | 12 | 28.8 | 1477 | 3552 | 0.008096385542 | 0.04163855422
IAConvert | 1 | 8 | 1995.4 | 1648.7 | -0.02019036631 | 41.28785694
Ijudge | 1 | 8 | 1994.3 | 1647.9 | -0.02020785219 | 41.30051963
IBConvert | 1 | 8 | 1994.6 | 1648.4 | -0.02021952629 | 41.32986713
 |  |  |  |  | #DIV/0! | #DIV/0!
 |  |  |  |  | #DIV/0! | #DIV/0!
 |  |  |  |  | #DIV/0! | #DIV/0!
 |  |  |  |  | #DIV/0! | #DIV/0!
 |  |  |  |  | #DIV/0! | #DIV/0!
 |  |  |  |  | #DIV/0! | #DIV/0!
 |  |  |  |  | #DIV/0! | #DIV/0!

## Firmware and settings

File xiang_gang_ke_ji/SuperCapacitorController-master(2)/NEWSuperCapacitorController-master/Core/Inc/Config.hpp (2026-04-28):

/**
 * @file Config.hpp
 * @author JIANG Yicheng RM2023
 * @brief
 * @version 0.1
 * @date 2023-01-23
 *
 * @copyright Copyright (c) 2023
 */

#define MAX_CAP_VOLTAGE 28.0f

#define SHORT_CIRCUIT_CURRENT 15.5f
#define SHORT_CIRCUIT_VOLTAGE 4.0f

#define I_LIMIT 22.5f

#define OVER_TEMP_TRIGGER_THRESHOLD 180
#define OVER_TEMP_RECOVER_THRESHOLD 200

#define LOW_BATTERY_VOLTAGE 20.92f
#define LOW_BATTERY_RECOVER_VOLTAGE 21.6f

#ifdef CALIBRATION_MODE
#define DEFAULT_REFEREE_POWER 37.0f
#else
#define DEFAULT_REFEREE_POWER 37.0f
#endif

#define ENERGY_BUFFER 50.0f

#define ADC_CHANNEL_COUNT 3
#define ADC_SAMPLE_COUNT 8
#define DIVIDED_BY_ADC_SAMPLE_COUNT (1.0f / ADC_SAMPLE_COUNT)

#define ADC_FILTER_ALPHA 0.5f

#define HRTIM_PERIOD 16000

#pragma once

#define configASSERT(x) \
    if (!(x))           \
        __asm volatile("bkpt ");

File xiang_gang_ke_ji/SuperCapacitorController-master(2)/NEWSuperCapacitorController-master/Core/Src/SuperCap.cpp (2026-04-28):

/**
 * @file SuperCap.cpp
 * @author JIANG Yicheng RM2023
 * @brief
 * @version 0.1
 * @date 2023-01-22
 *
 * @copyright Copyright (c) 2023
 */

#include "Buzzer.hpp"
#include "Calibration.hpp"
#include "Communication.hpp"
#include "Config.hpp"
#include "PowerManager.hpp"
#include "iwdg.h"
#include "main.h"

namespace SuperCap
{
static void loop()
{
    while (true)
    {
        __HAL_IWDG_RELOAD_COUNTER(&hiwdg);
        HAL_Delay(1);
    }
}

void configIWDG()
{
    hiwdg.Instance = IWDG;
    __HAL_IWDG_START(&hiwdg);
    IWDG_ENABLE_WRITE_ACCESS(&hiwdg);
    hiwdg.Instance->PR  = IWDG_PRESCALER_4;
    hiwdg.Instance->RLR = 1000;
    while ((hiwdg.Instance->SR & (IWDG_SR_WVU | IWDG_SR_RVU | IWDG_SR_PVU)) != 0x00u)
        ;
    __HAL_IWDG_RELOAD_COUNTER(&hiwdg);
}

void init()
{
    HAL_Delay(200);  // wait voltage stabilization

    /* initialize communication */
    Buzzer::init();

    /* check hardware id */
    static volatile uint32_t hardwareID = HAL_FLASHEx_OBGetUserData(OB_DATA_ADDRESS_DATA0);

    if (hardwareID != (uint32_t)HARDWARE_ID)
    {
#ifdef CALIBRATION_MODE
        while (HAL_FLASH_OB_Unlock() != HAL_OK)  // unlock flash option bytes
            __ASM volatile("bkpt ");

        while (HAL_FLASHEx_OBErase() != HAL_OK)  // erase option bytes
            __ASM volatile("bkpt ");

        FLASH_OBProgramInitTypeDef pOBInit;
        pOBInit.OptionType  = OPTIONBYTE_WRP | OPTIONBYTE_RDP | OPTIONBYTE_USER | OPTIONBYTE_DATA;
        pOBInit.WRPState    = OB_WRPSTATE_DISABLE;
        pOBInit.WRPPage     = 0xFFFFFFFF;
        pOBInit.RDPLevel    = OB_RDP_LEVEL_0;
        pOBInit.USERConfig  = OB_IWDG_SW | OB_STOP_NO_RST | OB_STDBY_NO_RST | OB_BOOT1_RESET | OB_VDDA_ANALOG_ON | OB_SRAM_PARITY_RESET;
        pOBInit.DATAAddress = OB_DATA_ADDRESS_DATA0;
        pOBInit.DATAData    = (uint8_t)HARDWARE_ID;        // set hardware id

        while (HAL_FLASHEx_OBProgram(&pOBInit) != HAL_OK)  // program option bytes
            __ASM volatile("bkpt ");

        while (HAL_FLASH_OB_Lock() != HAL_OK)  // lock flash option bytes
            __ASM volatile("bkpt ");

        while (HAL_FLASH_OB_Launch() != HAL_OK)  // launch option bytes
            __ASM volatile("bkpt ");

#endif
        Buzzer::play(1000);
        while (true)
            __ASM volatile("bkpt ");
    }

    /* initialize power manager */
    Buzzer::play(800, 500);

    Communication::init();

    HAL_Delay(600);

    PowerManager::init();

    configIWDG();
}

extern "C"
{
    void systemStart()
    {
        SuperCap::init();
        loop();
    }
}
}  // namespace SuperCap

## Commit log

2026-03-26 Initial upload
    [SuperCap2024Control_V1.1R_F3_ISOPWR.kicad_pcb, SuperCap2024Control_V1.1R_F3_ISOPWR.kicad_sch, SuperCap2024V1.2R_Power.kicad_pcb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]
2026-04-28 Add new files and update tutorial
    - Update 超电傻瓜式使用教程.md
    - Add 修改内容.md
    - Add SuperCapacitorController-master(2) project files
    - Add image assets
    - Add super_cap_extract_20260428
    [SuperCap2024Control_V1.1R_F3_ISOPWR.kicad_pcb, SuperCap2024Control_V1.1R_F3_ISOPWR.kicad_sch, SuperCap2024V1.2R_Power.kicad_pcb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]
2026-04-28 Add hardware files, STEP model, PDF report, and boom assets
    [24电容上壳.STEP, BOM_SuperCap2024Control_V1.1R_F3_ISOPWR_SuperCap2024Control_V1.1R_F3_ISOPWR_2025-11-23.xlsx, BOM_SuperCap2024铝基板.xlsx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]
